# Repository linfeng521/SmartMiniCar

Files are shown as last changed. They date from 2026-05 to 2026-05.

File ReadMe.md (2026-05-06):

# 练习项目三、1.3智能小车
## 一、项目思路
智能小车项目的整体思路是：以主控芯片为核心，结合电机驱动模块控制小车运动，通过传感器采集小车运行状态，再利用 PID 控制算法对小车的速度、方向或循迹过程进行实时调节，使小车能够更加稳定、准确地完成前进、转弯、避障或循迹等任务。
其中，PID 的作用是根据目标值和实际值之间的误差进行动态调整，从而提高小车运行的平稳性和控制精度。
## 二、项目功能
1. 小车运动控制功能
能够实现前进、后退、左转、右转和停止等基本动作。

2. PID 速度调节功能
通过 PID 算法对电机转速进行闭环控制，使小车保持稳定速度运行。
3. PID 方向修正功能
在循迹或直线行驶过程中，通过 PID 对偏差进行修正，提高行驶稳定性。
4. 循迹功能
通过红外传感器检测地面轨迹，小车能够沿指定路线自动行驶。
5. 避障功能
通过超声波等传感器检测前方障碍物，在接近障碍物时自动减速、停止或绕行。
6. 状态显示功能
可通过 OLED 或其他显示模块显示当前速度、运行模式、传感器状态等信息。
## 三、硬件组成
1. 主控模块
作为整个小车系统的核心，用于采集传感器信息、执行 PID 算法并输出控制信号。
> stm32f103c8t6
2. 电机驱动模块
用于驱动左右电机运转，实现小车前进、后退和转向。
TB6612FNG电机驱动模块(替代旧款L298N)
> 双路 H 桥电机驱动芯片,可以驱动两路直流电机
3. 直流减速电机
作为小车的动力来源，带动车轮运动。
2个轮趣MG370直流减速电机P34_12V 霍尔编码器
> 电机资料：https://pan.baidu.com/s/1y1XS6GmnZMquCIRk9muSQg 【WHEELTEC】
> 减速比：1:34
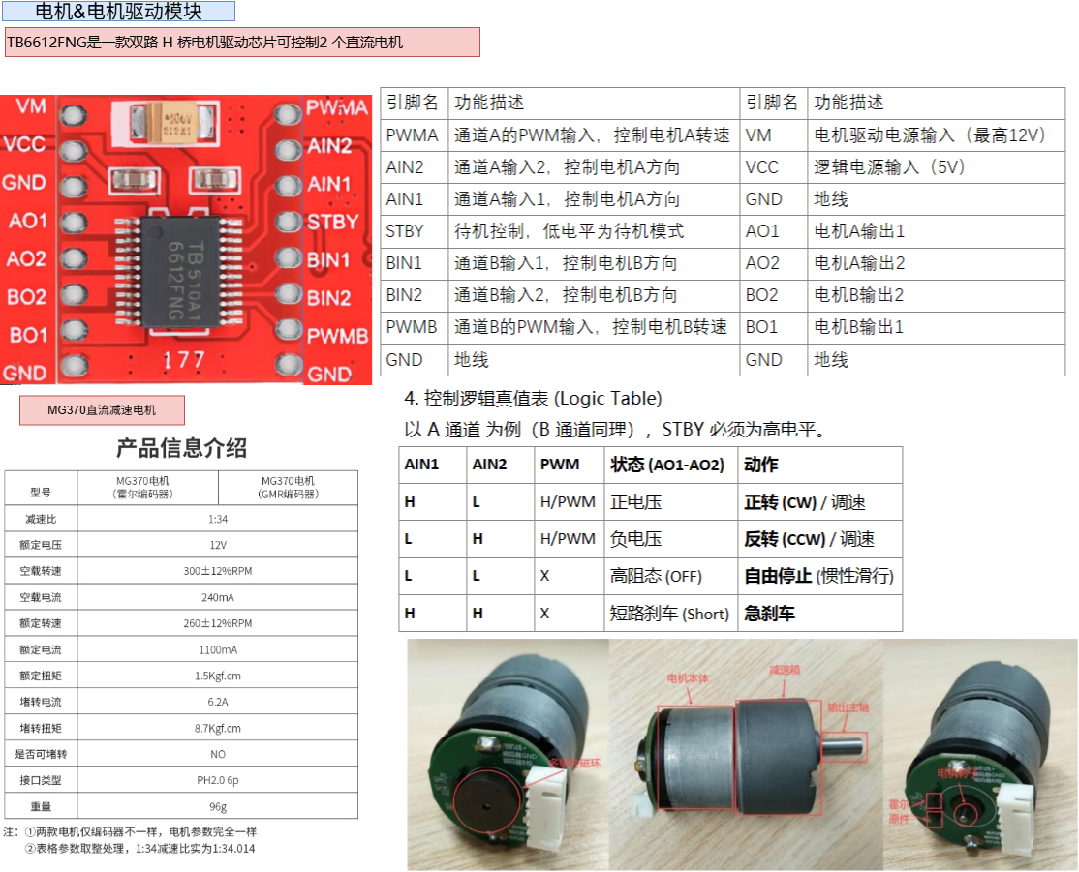
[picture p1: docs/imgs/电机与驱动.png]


4. 编码器模块
用于检测电机转速或车轮转动情况，为 PID 闭环控制提供反馈数据。
> 电机尾部霍尔编码器AB相
> 电机的编码器精度为 13
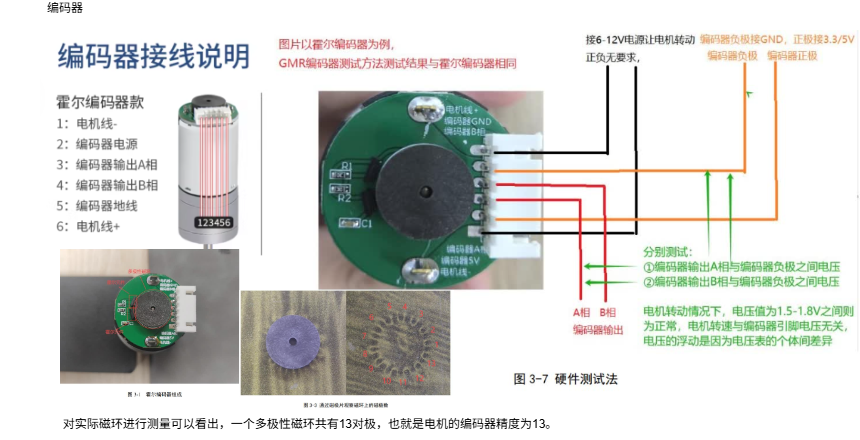
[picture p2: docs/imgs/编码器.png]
编码器

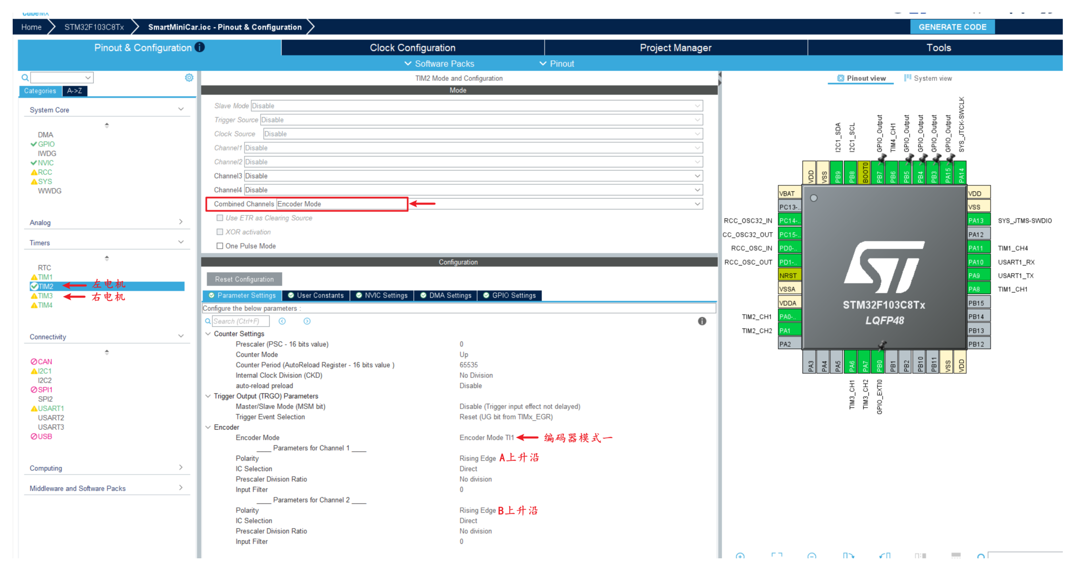
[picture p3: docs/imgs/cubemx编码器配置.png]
cubemx编码器配置


5. 霍尔转速模块
用于辅助检测电机转速，一圈一个脉冲

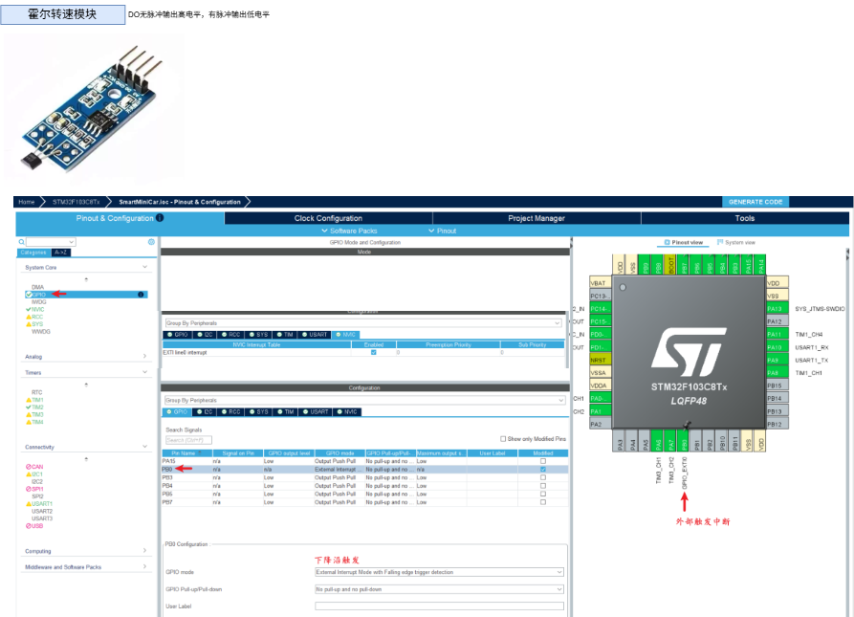
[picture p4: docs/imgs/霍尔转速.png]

~~ 5. 红外循迹传感器 ~~
用于检测地面黑线或路径，实现小车自动循迹。
6. 超声波模块
用于检测前方障碍物距离，实现避障功能。

> 超声波模块：HC-SR04超声波传感器

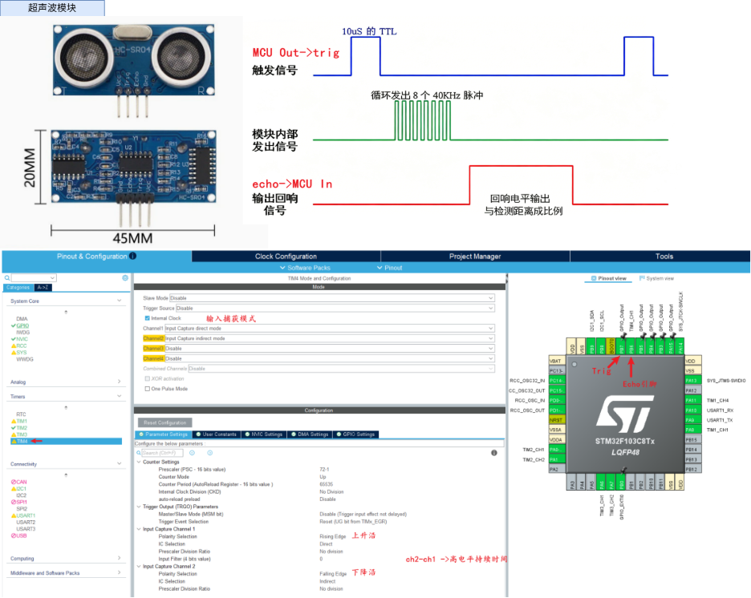
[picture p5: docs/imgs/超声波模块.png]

7. OLED 显示屏
用于显示速度、模式、传感器数据和运行状态。
> 屏幕：OLED 128*64 屏幕
8. 电源模块
为主控、电机驱动、传感器和显示模块提供稳定电源。
> 电源：德力普12V 1800mAh【3节一字型】
> 升降压模块：TPS63020 DCDC直流锂电池开关电源 2035升降压 5V输出输入3-20V

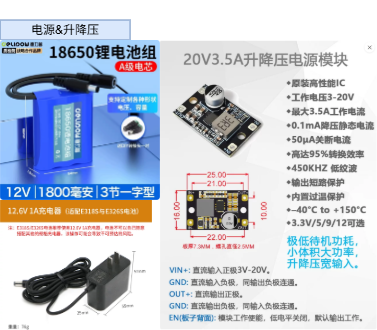
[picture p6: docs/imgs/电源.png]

9. 车体结构
包括底盘、车轮、电机固定架和各模块安装支架。
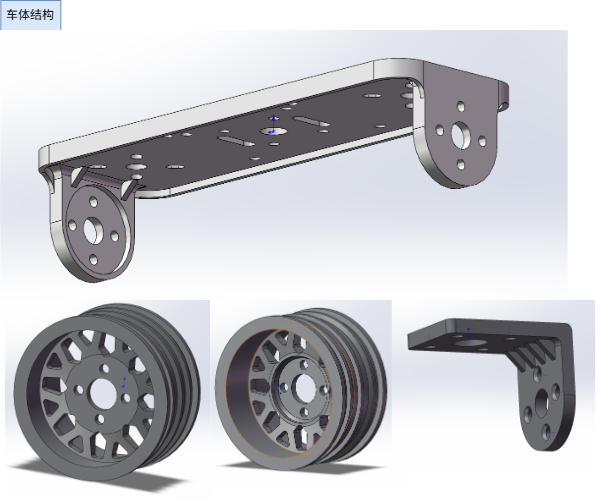
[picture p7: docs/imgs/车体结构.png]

## 四、软件组成

### 4.1 根据项目功能，引脚分配如下：
#### TB6612 电机驱动引脚

| 功能 | 引脚 | 说明 |
|---|---|---|
| PWMA | PA8 (TIM1_CH1) | 左电机 PWM，高级定时器支持 |
| PWMB | PA11 (TIM1_CH4) | 右电机 PWM |
| AIN1 | PB5 | 左电机方向控制1 |
| AIN2 | PB4 | 左电机方向控制2 |
| BIN1 | PB3 | 右电机方向控制1 |
| BIN2 | PA15 | 右电机方向控制2 |
| STBY | PA12 | 驱动使能，高电平有效(待定 现在直接使用接了3.3V) |

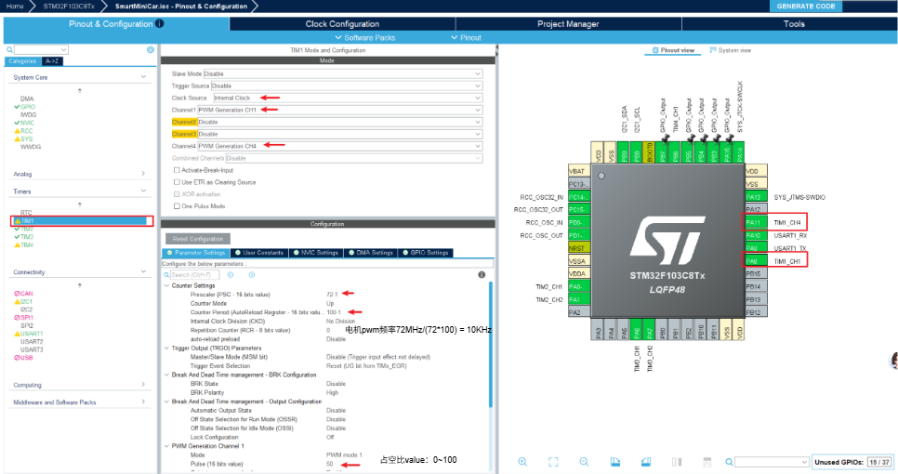
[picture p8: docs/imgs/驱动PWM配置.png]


#### 编码器引脚（霍尔编码器）

| 功能 | 引脚 | 说明 |
|---|---|---|
| 左编码器 A 相 | PA0 (TIM2_CH1) | TIM2 编码器模式 |
| 左编码器 B 相 | PA1 (TIM2_CH2) | TIM2 编码器模式 |
| 右编码器 A 相 | PA6 (TIM3_CH1) | TIM3 编码器模式 |
| 右编码器 B 相 | PA7 (TIM3_CH2) | TIM3 编码器模式 |

详见驱动模块：[编码器驱动](BSP/Encoder/encoder.c)
```c
// 启动定时器编码器模式
HAL_TIM_Encoder_Start(&htim2, TIM_CHANNEL_ALL);
HAL_TIM_Encoder_Start(&htim3, TIM_CHANNEL_ALL);

// 重置计数
__HAL_TIM_SET_COUNTER(&htim2, 0);
__HAL_TIM_SET_COUNTER(&htim3, 0);

//获取计数
__HAL_TIM_GET_COUNTER(&htim2);
__HAL_TIM_GET_COUNTER(&htim3)
```
#### 霍尔测速模块
无触发时为高电平，有触发时为低电平
| 功能 | 引脚 | 说明 |
|---|---|---|
| 电机霍尔测速器 | PB0 | GPIO EXTI0 外部中断输入，霍尔测速信号 |

[霍尔测速驱动](BSP/Hall/hall.c)

#### 超声波模块引脚

| 功能 | 引脚 | 说明 |
|---|---|---|
| Trig | PB7 | GPIO 输出，触发信号 |
| Echo | PB6 | GPIO 输入，回波信号(可接 TIM4 输入捕获) |

[超声波模块驱动](BSP/HCSR04/hcsr04.c)

#### OLED 显示屏引脚 && MPU6050 (I2C)

| 功能 | 引脚 | 说明 |
|---|---|---|
| SCL | PB8 (I2C1_SCL) | I2C1 时钟线 |
| SDA | PB9 (I2C1_SDA) | I2C1 数据线 |

#### 串口调试引脚

| 功能 | 引脚 | 说明 |
|---|---|---|
| uart_tx | PA9  | TX 数据线 |
| uart_rx | PA10 | RX 数据线 |

### 4.2 定时器配置

#### TIM1 — 电机 PWM

- Clock Source: Internal Clock
- Channel1 (PWMA): PWM Generation CH1
- Channel4 (PWMB): PWM Generation CH4
- Prescaler (PSC): 71 → 计数频率 = 72MHz / 72 = 1 MHz
- Counter Period (ARR): 99 → PWM 频率 = 1MHz / 100 = 10 kHz
- Pulse (CCR): 0~999 → 占空比 0~100%

> PWM 频率选择: TB6612 支持 0~100kHz，10kHz 是常用值，电机声音较小

#### TIM2 — 左编码器

- Combined Channel: Encoder Mode TI1
- Prescaler (PSC): 0
- Counter Period (ARR): 65535 (16位满量程)
- Encoder Polarity: Rising / Rising
- 计数模式: Up

#### TIM3 — 右编码器

- 同 TIM2 配置

#### TIM4 — 超声波输入捕获

- TIM4_CH1：Input Capture Direct Mode（直接模式）
  极性：Rising Edge 上升沿
- TIM4_CH2：Input Capture Indirect Mode（间接模式）
  极性：Falling Edge 下降沿
- Prescaler: 71 → 计数频率 = 1 MHz，1计数 = 1μs
- 用于测量 Echo 高电平持续时间

## 五、分模块测试
1、电机测试（PWM）

2、编码器测试

3、超声波测距测试

4、OLED 显示测试

5、霍尔转速测试

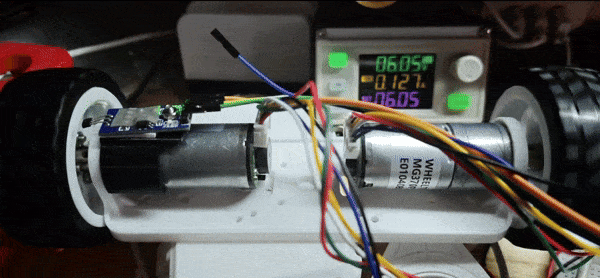
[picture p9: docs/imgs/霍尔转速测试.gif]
霍尔转速


6、总体功能测试
```c
while (1)
  {
    uint32_t now = HAL_GetTick();

    /*串口命令*/
    if (uart_cmd_ready != 0U)
    {
      char command[UART_COMMAND_MAX_LEN];

      __disable_irq();
      strncpy(command, uart_cmd_line, sizeof(command));
      uart_cmd_ready = 0U;
      __enable_irq();

      printf("recv:%s\r\n", command);

      Motor_ParseCommand(command);
    }

    /*编码器*/
    if ((now - encoder_tick) >= 100)
    {
      encoder_tick = now;

      left_rps = Encoder_GetRPS(ENCODER_LEFT);
      right_rps = Encoder_GetRPS(ENCODER_RIGHT);

      printf("encoder:left_rps=%f,right_rps=%f\r\n", left_rps, right_rps);
    }

    /*霍尔*/
    if ((now - hall_tick) >= 100)
    {
      hall_tick = now;

      printf("hall:PulseCnt=%d,left_rpm=%d,freq=%f\r\n", Hall_GetPulse(), Hall_GetRPM(), Hall_GetRPS());
    }

    /*超声波*/
    if ((now - ultrasonic_tick) >= 50)
    {
      ultrasonic_tick = now;

      HCSR04_Trigger();
      distance_cm = HCSR04_GetDistanceCm();

      printf("dist=%.1fcm\r\n", distance_cm);
    }

    /*OLED显示*/
    if ((now - oled_tick) >= 200)
    {
      oled_tick = now;
      // 左电机编码器(tim2 encoder)
      sprintf(oled_buf, "ML:%5.2f rps", left_rps);
      OLED_ShowString(0, 0, oled_buf, 16, 0);
      // 右电机编码器(tim3 encoder)
      sprintf(oled_buf, "MR:%5.2f rps", right_rps);
      OLED_ShowString(0, 2, oled_buf, 16, 0);
      // 左电机霍尔转速（exti0)
      sprintf(oled_buf, "LH:%5.2f rps", Hall_GetRPS());
      OLED_ShowString(0, 4, oled_buf, 16, 0);
      // 超声波测距(tim3 ic)
      sprintf(oled_buf, "D:%5.1fCM", distance_cm);
      OLED_ShowString(0, 6, oled_buf, 16, 0);
    }
```
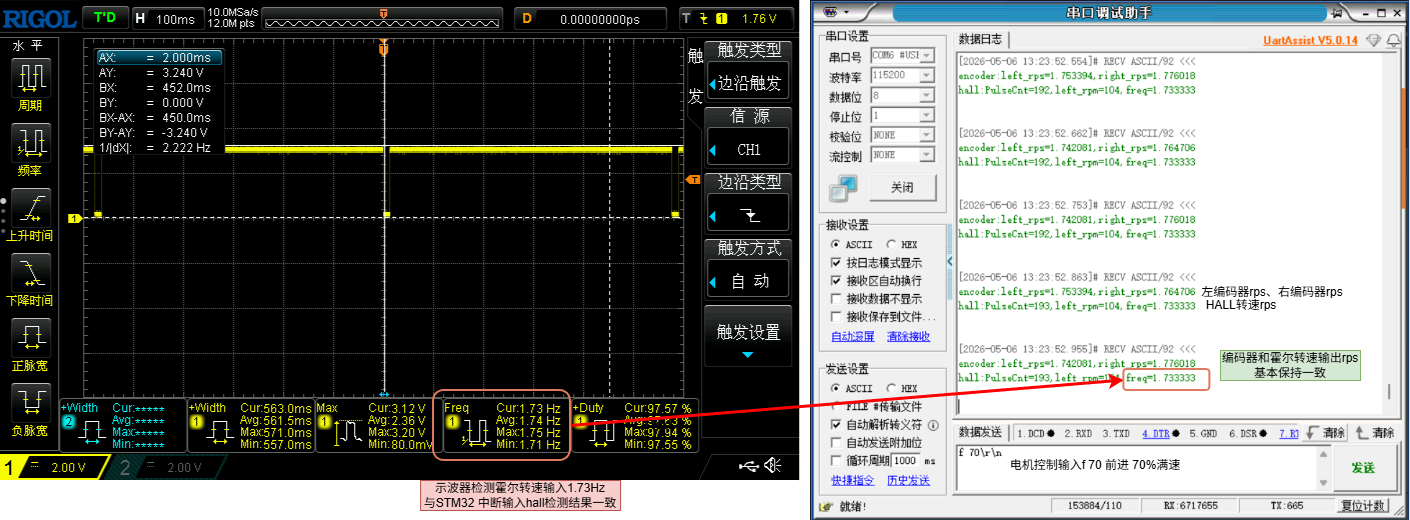
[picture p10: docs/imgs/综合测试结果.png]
测试结果


拍照

[阶段1视频](https://github.com/linfeng521/SmartMiniCar/blob/main/docs/imgs/阶段1.mp4)

[在线drawio文档笔记](https://app.diagrams.net/#Hlinfeng521/SmartMiniCar/main/docs/智能小车.drawio)

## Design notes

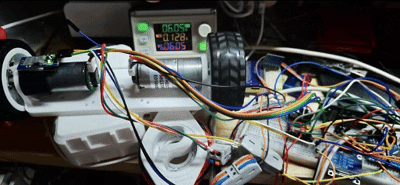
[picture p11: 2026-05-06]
docs/imgs/948157eb1a8de07d441068f1ed50d3bd.gif

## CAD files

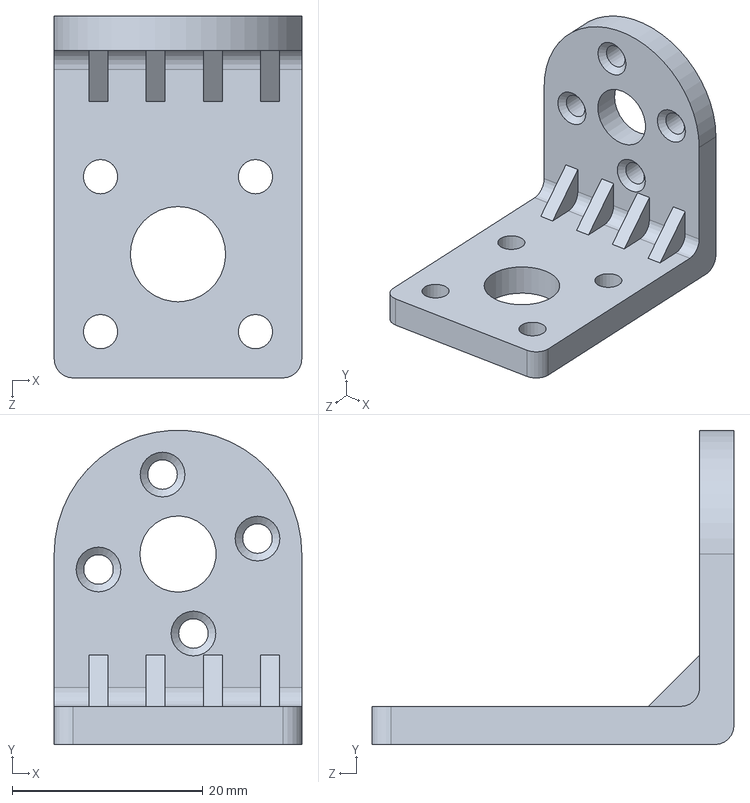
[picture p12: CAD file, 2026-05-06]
docs/MG370直流减速电机支架加厚加肋板.SLDPRT
26.0 x 33.0 x 38.0 mm

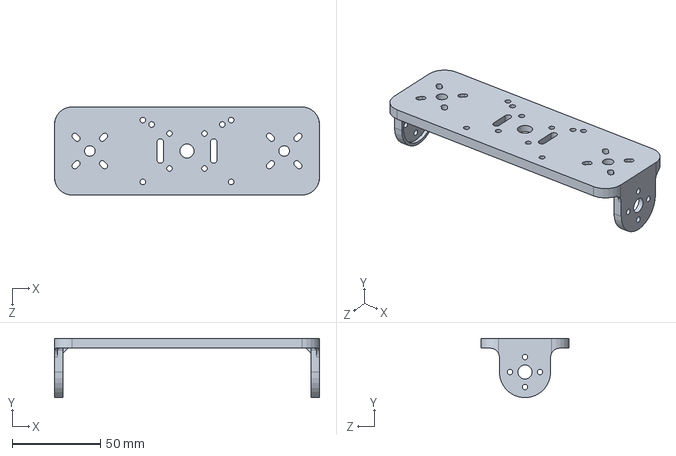
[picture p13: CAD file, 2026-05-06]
docs/平衡车底板一体.SLDPRT
150.0 x 33.6 x 50.0 mm

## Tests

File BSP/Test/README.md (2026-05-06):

# 模块化测试系统使用指南

## 📁 文件结构

```
BSP/
├── Test/
│   ├── test.h              # 测试接口头文件
│   ├── test.c              # 测试实现文件
│   ├── test_example.c      # 使用示例
│   └── README.md           # 本文档
├── Motor/
│   ├── motor.h
│   ├── motor.c
│   └── motor_test.md       # 电机测试指南
├── Encoder/
│   ├── encoder.h
│   └── encoder.c
└── HCSR04/
    ├── hcsr04.h
    └── hcsr04.c
```

## 🚀 快速开始

### 1. 添加文件到工程

在 Keil MDK 或 STM32CubeIDE 中：
1. 将 `test.c` 添加到工程
2. 将 `BSP/Test` 路径添加到 Include Paths

### 2. 在 main.c 中添加代码

```c
#include "test.h"

int main(void)
{
    // ... HAL 初始化 ...
    
    Motor_Init();
    Encoder_Init();
    HCSR04_Init();
    
    Test_Init();        // 初始化测试系统
    Test_PrintMenu();   // 显示测试菜单
    
    while (1)
    {
        // 方法1: 直接调用
        Test_Motor_Left();
        HAL_Delay(3000);
        
        // 方法2: 通过枚举
        Test_RunModule(TEST_MOTOR_RIGHT);
        HAL_Delay(3000);
    }
}
```

### 3. 通过串口控制（推荐）

发送单个字符命令：
- `0` - 测试左电机
- `1` - 测试右电机
- `2` - 测试前进
- `3` - 测试后退
- `4` - 测试左转
- `5` - 测试右转
- `6` - 测试原地左旋
- `7` - 测试原地右旋
- `8` - 测试左编码器
- `9` - 测试右编码器
- `a` - 测试双编码器
- `b` - 测试超声波
- `c` - 电机编码器同步测试
- `d` - 运行所有测试
- `m` - 显示菜单

## 📋 测试模块说明

### 电机测试

#### 1. 单电机测试 (`Test_Motor_Left` / `Test_Motor_Right`)
**目的**: 判断左右电机定义是否正确

**步骤**:
1. 调用 `Test_Motor_Left()`
2. 观察：应该是**左侧**电机转动
3. 如果是右侧转动，说明定义颠倒了

**预期输出**:
```
[测试] 左电机测试
左电机将以 50% 速度运行 2000 ms
请观察：应该是【左侧】电机转动
左电机测试完成
```

#### 2. 前进/后退测试 (`Test_Motor_Forward` / `Test_Motor_Backward`)
**目的**: 验证电机方向是否正确

**判断标准**:
- ✅ 前进：小车向前移动
- ✅ 后退：小车向后移动
- ❌ 如果相反，需要调整电机方向引脚

#### 3. 转向测试 (`Test_Motor_TurnLeft` / `Test_Motor_TurnRight`)
**目的**: 验证转向逻辑

**判断标准**:
- ✅ 左转：小车向左转弯（左轮慢，右轮快）
- ✅ 右转：小车向右转弯（右轮慢，左轮快）
- ❌ 如果相反，说明左右电机定义颠倒

#### 4. 原地旋转测试 (`Test_Motor_RotateLeft` / `Test_Motor_RotateRight`)
**目的**: 验证原地旋转功能

**判断标准**:
- ✅ 左旋：逆时针旋转（左轮后退，右轮前进）
- ✅ 右旋：顺时针旋转（左轮前进，右轮后退）

### 编码器测试

#### 1. 单编码器测试 (`Test_Encoder_Left` / `Test_Encoder_Right`)
**目的**: 验证编码器方向

**预期输出**:
```
[测试] 左编码器测试
左电机将前进 2000 ms，测量编码器计数
左编码器计数: 1234
方向: 前进
✓ 编码器方向正确（前进为正）
```

**判断标准**:
- ✅ 前进时计数为**正数**
- ❌ 前进时计数为**负数** → 编码器接线反了
- ❌ 计数为 0 → 检查编码器接线或 CubeMX 配置

#### 2. 双编码器同步测试 (`Test_Encoder_Both`)
**目的**: 检查两轮速度是否一致

**预期输出**:
```
[测试] 双编码器同步测试
小车将前进 2000 ms，测量两个编码器
左编码器: 1234
右编码器: 1256
差异: -22 (-1.8%)
✓ 两个编码器方向都正确
✓ 两轮速度基本一致
```

**判断标准**:
- ✅ 差异 < 10% → 速度基本一致
- ⚠️ 差异 > 10% → 可能需要 PID 校准

#### 3. 电机编码器同步测试 (`Test_Motor_Encoder_Sync`)
**目的**: 全面验证电机和编码器匹配

**测试流程**:
1. 前进 1 秒，记录编码器值
2. 后退 1 秒，记录编码器值
3. 分析结果

**预期输出**:
```
[测试] 电机编码器同步测试
1. 测试前进...
   左: 1234, 右: 1256
2. 测试后退...
   左: -1230, 右: -1250

结果分析:
✓ 电机和编码器方向完全匹配
```

### 传感器测试

#### HC-SR04 超声波测试 (`Test_HCSR04`)
**目的**: 验证超声波测距功能

**预期输出**:
```
[测试] HC-SR04 超声波测试
将连续测量 10 次距离
[1] 距离: 25.3 cm
[2] 距离: 25.5 cm
[3] 距离: 25.2 cm
...
```

**判断标准**:
- ✅ 能测量到距离（2-400cm）
- ✅ 数值稳定，波动小
- ❌ 显示 -1.0 → 超出测量范围
- ❌ 超时 → 检查接线或 CubeMX 配置

## 🔧 常见问题排查

### 问题1: 左右电机颠倒

**现象**: 调用 `Test_Motor_Left()` 时右侧电机转动

**解决方法**: 在 `motor.h` 中交换 A 和 B 的引脚定义
```c
// 交换前
#define MOTOR_AIN1_PIN GPIO_PIN_5
#define MOTOR_BIN1_PIN GPIO_PIN_3

// 交换后
#define MOTOR_AIN1_PIN GPIO_PIN_3
#define MOTOR_BIN1_PIN GPIO_PIN_5
```

### 问题2: 前进变后退

**现象**: 调用 `Test_Motor_Forward()` 时小车后退

**解决方法**: 在 `motor.c` 的 `Motor_SetDirection()` 中交换 SET 和 RESET

### 问题3: 编码器计数为负

**现象**: 前进时编码器显示负数

**解决方法**: 
1. 交换编码器 A/B 相接线
2. 或在 CubeMX 中修改编码器模式（TI1/TI2 互换）

### 问题4: 编码器无计数

**现象**: 电机转动但编码器计数为 0

**排查步骤**:
1. 检查编码器供电（通常 3.3V 或 5V）
2. 检查 A/B 相接线是否正确
3. 检查 CubeMX 中定时器配置（Encoder Mode）
4. 用示波器测量编码器输出波形

### 问题5: 超声波无数据

**现象**: 超声波测试一直超时

**排查步骤**:
1. 检查 TRIG 和 ECHO 接线
2. 检查 CubeMX 中 TIM4 配置（Input Capture）
3. 确认前方有障碍物（2-400cm 范围内）
4. 检查中断是否使能

## 💡 使用技巧

### 1. 快速诊断流程

```c
// 在 main 函数中添加
Test_Init();

// 步骤1: 测试左右电机
Test_Motor_Left();
HAL_Delay(3000);
Test_Motor_Right();
HAL_Delay(3000);

// 步骤2: 测试前进
Test_Motor_Forward();
HAL_Delay(3000);

// 步骤3: 测试编码器同步
Test_Motor_Encoder_Sync();

// 根据输出结果判断问题
```

### 2. 串口交互式测试（推荐）

```c
// 在串口接收回调中
void HAL_UART_RxCpltCallback(UART_HandleTypeDef *huart)
{
    if (huart->Instance == USART1) {
        char cmd = rx_buffer[0];
        
        if (cmd >= '0' && cmd <= '9') {
            Test_RunModule((Test_Module_TypeDef)(cmd - '0'));
        } else if (cmd == 'a' || cmd == 'A') {
            Test_RunModule(TEST_ENCODER_BOTH);
        }
        // ... 其他命令
        
        HAL_UART_Receive_IT(&huart1, rx_buffer, 1);
    }
}
```

### 3. 自动化测试

```c
// 开机自动运行所有测试
Test_Init();
Test_RunModule(TEST_ALL);
```

## 📊 测试报告示例

```
========================================
  SmartMiniCar 模块测试系统
========================================

[测试] 左电机测试
✓ 左侧电机正常转动

[测试] 右电机测试
✓ 右侧电机正常转动

[测试] 前进测试
✓ 小车正常前进

[测试] 双编码器同步测试
左编码器: 1234
右编码器: 1256
差异: -22 (-1.8%)
✓ 两个编码器方向都正确
✓ 两轮速度基本一致

[测试] HC-SR04 超声波测试
[1] 距离: 25.3 cm
[2] 距离: 25.5 cm
✓ 超声波工作正常

========================================
测试结论: 所有模块工作正常
========================================
```

## 🎯 下一步

测试通过后，可以开始：
1. 实现 PID 速度控制
2. 实现避障功能
3. 实现循迹功能
4. 实现蓝牙/WiFi 控制

参考 `motor_test.md` 获取更多电机调试信息。

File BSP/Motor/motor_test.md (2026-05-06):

# 电机测试指南

## 如何判断左右电机是否颠倒

### 测试步骤：

1. **单独测试左电机**
   ```c
   Motor_TestLeftMotor(50, 2000);  // 左电机以50%速度运行2秒
   ```
   - 观察：应该是**左侧**电机转动
   - 如果是右侧电机转动，说明定义颠倒了

2. **单独测试右电机**
   ```c
   Motor_TestRightMotor(50, 2000);  // 右电机以50%速度运行2秒
   ```
   - 观察：应该是**右侧**电机转动
   - 如果是左侧电机转动，说明定义颠倒了

3. **测试前进**
   ```c
   Motor_Forward(50);  // 前进
   HAL_Delay(2000);
   Motor_StopAll();
   ```
   - 观察：两个电机应该**同向转动**，小车**前进**
   - 如果小车后退，说明两个电机方向都反了
   - 如果小车原地转，说明一个电机方向反了

4. **测试转向**
   ```c
   Motor_TurnLeft(50);   // 左转
   HAL_Delay(2000);
   Motor_StopAll();
   ```
   - 观察：小车应该**向左转**
   - 如果向右转，说明左右电机定义颠倒了

## 如果发现问题，修复方法：

### 方法1：交换硬件定义（推荐）

在 `motor.h` 中交换 A 和 B 的引脚定义：

```c
// 原来的定义
#define MOTOR_AIN1_PIN GPIO_PIN_5    // 左电机
#define MOTOR_AIN1_PORT GPIOB
#define MOTOR_AIN2_PIN GPIO_PIN_4
#define MOTOR_AIN2_PORT GPIOB

#define MOTOR_BIN1_PIN GPIO_PIN_3    // 右电机
#define MOTOR_BIN1_PORT GPIOB
#define MOTOR_BIN2_PIN GPIO_PIN_15
#define MOTOR_BIN2_PORT GPIOA

// 如果颠倒了，改成：
#define MOTOR_AIN1_PIN GPIO_PIN_3    // 交换
#define MOTOR_AIN1_PORT GPIOB
#define MOTOR_AIN2_PIN GPIO_PIN_15
#define MOTOR_AIN2_PORT GPIOA

#define MOTOR_BIN1_PIN GPIO_PIN_5    // 交换
#define MOTOR_BIN1_PORT GPIOB
#define MOTOR_BIN2_PIN GPIO_PIN_4
#define MOTOR_BIN2_PORT GPIOB
```

### 方法2：交换 PWM 通道

在 `motor.c` 的 `Motor_SetPWM()` 函数中交换通道：

```c
switch (motor) {
case MOTOR_LEFT:
    __HAL_TIM_SET_COMPARE(&htim1, TIM_CHANNEL_4, pwm);  // 改成 CHANNEL_4
    break;

case MOTOR_RIGHT:
    __HAL_TIM_SET_COMPARE(&htim1, TIM_CHANNEL_1, pwm);  // 改成 CHANNEL_1
    break;
}
```

### 方法3：如果只是方向反了

如果左右没颠倒，但前进变后退，在 `Motor_SetDirection()` 中交换 SET 和 RESET：

```c
case MOTOR_DIR_FORWARD:
    // 把 GPIO_PIN_SET 和 GPIO_PIN_RESET 互换
    HAL_GPIO_WritePin(MOTOR_AIN1_PORT, MOTOR_AIN1_PIN, GPIO_PIN_RESET);
    HAL_GPIO_WritePin(MOTOR_AIN2_PORT, MOTOR_AIN2_PIN, GPIO_PIN_SET);
    break;
```

## 编码器方向测试

测试编码器是否与电机方向匹配：

```c
Encoder_ResetAll();
Motor_Forward(50);
HAL_Delay(1000);
Motor_StopAll();

int16_t left_count = Encoder_GetDeltaCount(ENCODER_LEFT);
int16_t right_count = Encoder_GetDeltaCount(ENCODER_RIGHT);

printf("Left: %d, Right: %d\n", left_count, right_count);
```

- 前进时，两个编码器计数应该都是**正数**
- 如果某个是负数，说明该编码器接线反了，或者在 CubeMX 中配置反了

## 串口命令测试

通过串口发送以下命令测试：

- `F 50` - 前进，速度50%
- `B 50` - 后退，速度50%
- `L 50` - 左转
- `R 50` - 右转
- `RL 50` - 原地左旋
- `RR 50` - 原地右旋
- `M 30 50` - 左轮30%，右轮50%
- `STOP` - 停止

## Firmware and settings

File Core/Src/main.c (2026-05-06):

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
/* Includes ------------------------------------------------------------------*/
#include "main.h"
#include "i2c.h"
#include "tim.h"
#include "usart.h"
#include "gpio.h"

/* USER CODE BEGIN Includes */
#include <stdio.h>
#include <string.h>
#include "encoder.h"
#include "hall.h"
#include "motor.h"
#include "hcsr04.h"
#include "ssd1306.h"
/* USER CODE END Includes */

/* USER CODE BEGIN PD */
#define UART_COMMAND_MAX_LEN 64

/* USER CODE END PD */


/* USER CODE BEGIN PV */
static uint8_t uart_rx_byte;
static char uart_rx_line[UART_COMMAND_MAX_LEN];
static char uart_cmd_line[UART_COMMAND_MAX_LEN];
static volatile uint8_t uart_rx_index = 0;
static volatile uint8_t uart_cmd_ready = 0;

uint32_t hall_tick = 0;
uint32_t encoder_tick = 0;
uint32_t oled_tick = 0;
uint32_t ultrasonic_tick = 0;
char oled_buf[36] = ""; // oled显示

float left_rps = 0.0f;
float right_rps = 0.0f;
float distance_cm = 0.0f;

/* USER CODE END PV */

void SystemClock_Config(void);
/* USER CODE BEGIN PFP */
static void UART_StartReceiveIT(void);

/* USER CODE END PFP */

/* USER CODE BEGIN 0 */
// 串口重定向
int fputc(int ch, FILE *f)
{
  HAL_UART_Transmit(&huart1, (uint8_t *)&ch, 1, HAL_MAX_DELAY);
  return ch;
}

// 启动串口1的中断接收
static void UART_StartReceiveIT(void)
{
  if (HAL_UART_Receive_IT(&huart1, &uart_rx_byte, 1) != HAL_OK)
  {
    Error_Handler();
  }
}

// exti0 中断回调
void HAL_GPIO_EXTI_Callback(uint16_t GPIO_Pin)
{
  Hall_EXTI_Callback(GPIO_Pin);
}

/* USER CODE END 0 */

/**
 * @brief  The application entry point.
 * @retval int
 */
int main(void)
{

  /* MCU Configuration--------------------------------------------------------*/

  /* Reset of all peripherals, Initializes the Flash interface and the Systick. */
  HAL_Init();

  /* Configure the system clock */
  SystemClock_Config();

  /* Initialize all configured peripherals */
  MX_GPIO_Init();
  MX_I2C1_Init();
  MX_TIM1_Init();
  MX_TIM2_Init();
  MX_TIM3_Init();
  MX_TIM4_Init();
  MX_USART1_UART_Init();
  /* USER CODE BEGIN 2 */
  // 编码器初始化
  Encoder_Init();
  // 超声波测距初始化
  HCSR04_Init();
  // 左右减速电机&驱动模块初始化
  Motor_Init();
  // 配置 USART2 接收中断
  UART_StartReceiveIT();
  printf("UART motor control ready\r\n");
  printf("Commands: STOP | BRAKE | F 60 | B 60 | L 60 | R 60 | RL 60 | RR 60 | M -30 50\r\n");

  if (OLED_Init(&hi2c1) != HAL_OK)
  {
    Error_Handler();
  }
  OLED_Clear();
  /* USER CODE END 2 */

  /* Infinite loop */
  /* USER CODE BEGIN WHILE */
  while (1)
  {
    uint32_t now = HAL_GetTick();

    /*串口命令*/
    if (uart_cmd_ready != 0U)
    {
      char command[UART_COMMAND_MAX_LEN];

      __disable_irq();
      strncpy(command, uart_cmd_line, sizeof(command));
      uart_cmd_ready = 0U;
      __enable_irq();

      printf("recv:%s\r\n", command);

      Motor_ParseCommand(command);
    }

    /*编码器*/
    if ((now - encoder_tick) >= 100)
    {
      encoder_tick = now;

      left_rps = Encoder_GetRPS(ENCODER_LEFT);
      right_rps = Encoder_GetRPS(ENCODER_RIGHT);

      printf("encoder:left_rps=%f,right_rps=%f\r\n", left_rps, right_rps);
    }

    /*霍尔*/
    if ((now - hall_tick) >= 100)
    {
      hall_tick = now;

      printf("hall:PulseCnt=%d,left_rpm=%d,freq=%f\r\n", Hall_GetPulse(), Hall_GetRPM(), Hall_GetRPS());
    }

    /*超声波*/
    if ((now - ultrasonic_tick) >= 50)
    {
      ultrasonic_tick = now;

      HCSR04_Trigger();
      distance_cm = HCSR04_GetDistanceCm();

      printf("dist=%.1fcm\r\n", distance_cm);
    }

    /*OLED显示*/
    if ((now - oled_tick) >= 200)
    {
      oled_tick = now;
      // 左电机编码器(tim2 encoder)
      sprintf(oled_buf, "ML:%5.2f rps", left_rps);
      OLED_ShowString(0, 0, oled_buf, 16, 0);
      // 右电机编码器(tim3 encoder)
      sprintf(oled_buf, "MR:%5.2f rps", right_rps);
      OLED_ShowString(0, 2, oled_buf, 16, 0);
      // 左电机霍尔转速（exti0)
      sprintf(oled_buf, "LH:%5.2f rps", Hall_GetRPS());
      OLED_ShowString(0, 4, oled_buf, 16, 0);
      // 超声波测距(tim3 ic)
      sprintf(oled_buf, "D:%5.1fCM", distance_cm);
      OLED_ShowString(0, 6, oled_buf, 16, 0);
    }

    /* USER CODE END WHILE */

    /* USER CODE BEGIN 3 */
  }
  /* USER CODE END 3 */
}

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
/* USER CODE BEGIN 4 */
void HAL_UART_RxCpltCallback(UART_HandleTypeDef *huart)
{
  if (huart->Instance == USART1)
  {
    if ((uart_rx_byte == '\r') || (uart_rx_byte == '\n'))
    {
      if (uart_rx_index > 0U)
      {
        uart_rx_line[uart_rx_index] = '\0';
        if (uart_cmd_ready == 0U)
        {
          strncpy(uart_cmd_line, uart_rx_line, UART_COMMAND_MAX_LEN);
          uart_cmd_ready = 1U;
        }
        uart_rx_index = 0U;
      }
    }
    else if (uart_rx_index < (UART_COMMAND_MAX_LEN - 1U))
    {
      uart_rx_line[uart_rx_index++] = (char)uart_rx_byte;
    }
    else
    {
      uart_rx_index = 0U;
    }

    // 继续接收
    HAL_UART_Receive_IT(&huart1, &uart_rx_byte, 1);
  }
}

void HAL_UART_ErrorCallback(UART_HandleTypeDef *huart)
{
  if (huart->Instance == USART1)
  {
    uart_rx_index = 0U;
    UART_StartReceiveIT();
  }
}

/* USER CODE END 4 */
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


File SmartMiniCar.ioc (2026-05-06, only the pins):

Mcu.UserName=STM32F103C8Tx
PA0-WKUP.Signal=S_TIM2_CH1_ETR
PA1.Signal=S_TIM2_CH2
PA10.Signal=USART1_RX
PA11.Signal=S_TIM1_CH4
PA13.Signal=SYS_JTMS-SWDIO
PA14.Signal=SYS_JTCK-SWCLK
PA15.Signal=GPIO_Output
PA6.Signal=S_TIM3_CH1
PA7.Signal=S_TIM3_CH2
PA8.Signal=S_TIM1_CH1
PA9.Signal=USART1_TX
PB0.Signal=GPXTI0
PB3.Signal=GPIO_Output
PB4.Signal=GPIO_Output
PB5.Signal=GPIO_Output
PB6.Signal=S_TIM4_CH1
PB7.Signal=GPIO_Output
PB8.Signal=I2C1_SCL
PB9.Signal=I2C1_SDA
PC14-OSC32_IN.Signal=RCC_OSC32_IN
PC15-OSC32_OUT.Signal=RCC_OSC32_OUT
PD0-OSC_IN.Signal=RCC_OSC_IN
PD1-OSC_OUT.Signal=RCC_OSC_OUT

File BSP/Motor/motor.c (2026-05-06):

/**
  ******************************************************************************
  * @file    motor.c
  * @brief   TB6612 电机驱动实现
  * @note    PWM 频率: 72MHz / 72 / 100 = 10kHz
  ******************************************************************************
  */

#include "motor.h"

#include <ctype.h>
#include <stdio.h>
#include <stdlib.h>
#include <string.h>

// 限制速度在有效 PWM 范围内。
static int Motor_ClampPercent(int value)
{
    
    if (value > MOTOR_PWM_MAX) {
        return MOTOR_PWM_MAX;
    }

    if (value < -MOTOR_PWM_MAX) {
        return -MOTOR_PWM_MAX;
    }

    return value;
}

static void Motor_ToUpperToken(char *token)
{
    // 统一转成大写，方便命令匹配。
    while (*token != '\0') {
        *token = (char)toupper((unsigned char)*token);
        token++;
    }
}

// 初始化电机：先启动 PWM，再让电机停住。
void Motor_Init(void)
{
    HAL_TIM_PWM_Start(&htim1, TIM_CHANNEL_1);
    HAL_TIM_PWM_Start(&htim1, TIM_CHANNEL_4);
    Motor_StopAll();
}

// 设置某个电机的方向。
static void Motor_SetDirection(Motor_TypeDef motor, Motor_Direction_TypeDef dir)
{
    // 通过 TB6612 的方向引脚控制前进、后退和停止。
    switch (motor) {
    case MOTOR_LEFT:
        switch (dir) {
        case MOTOR_DIR_FORWARD:
					// 1 0正转
            HAL_GPIO_WritePin(MOTOR_AIN1_PORT, MOTOR_AIN1_PIN, GPIO_PIN_SET);
            HAL_GPIO_WritePin(MOTOR_AIN2_PORT, MOTOR_AIN2_PIN, GPIO_PIN_RESET);
            break;

        case MOTOR_DIR_BACKWARD:
					// 0 1反转
            HAL_GPIO_WritePin(MOTOR_AIN1_PORT, MOTOR_AIN1_PIN, GPIO_PIN_RESET);
            HAL_GPIO_WritePin(MOTOR_AIN2_PORT, MOTOR_AIN2_PIN, GPIO_PIN_SET);
            break;

        case MOTOR_DIR_STOP:
					// 0 0 自由停止(惯性滑行）
        default:
            HAL_GPIO_WritePin(MOTOR_AIN1_PORT, MOTOR_AIN1_PIN, GPIO_PIN_RESET);
            HAL_GPIO_WritePin(MOTOR_AIN2_PORT, MOTOR_AIN2_PIN, GPIO_PIN_RESET);
            break;
        }
        break;

    case MOTOR_RIGHT:
        switch (dir) {
        case MOTOR_DIR_FORWARD:
            HAL_GPIO_WritePin(MOTOR_BIN1_PORT, MOTOR_BIN1_PIN, GPIO_PIN_SET);
            HAL_GPIO_WritePin(MOTOR_BIN2_PORT, MOTOR_BIN2_PIN, GPIO_PIN_RESET);
            break;

        case MOTOR_DIR_BACKWARD:
            HAL_GPIO_WritePin(MOTOR_BIN1_PORT, MOTOR_BIN1_PIN, GPIO_PIN_RESET);
            HAL_GPIO_WritePin(MOTOR_BIN2_PORT, MOTOR_BIN2_PIN, GPIO_PIN_SET);
            break;

        case MOTOR_DIR_STOP:
        default:
            HAL_GPIO_WritePin(MOTOR_BIN1_PORT, MOTOR_BIN1_PIN, GPIO_PIN_RESET);
            HAL_GPIO_WritePin(MOTOR_BIN2_PORT, MOTOR_BIN2_PIN, GPIO_PIN_RESET);
            break;
        }
        break;

    default:
        break;
    }
}
// 设置 PWM 占空比。
void Motor_SetPWM(Motor_TypeDef motor, uint16_t pwm)
{
    // 更新对应 PWM 通道的比较值。
    if (pwm > MOTOR_PWM_MAX) {
        pwm = MOTOR_PWM_MAX;
    }

    switch (motor) {
    case MOTOR_LEFT:
        __HAL_TIM_SET_COMPARE(&htim1, TIM_CHANNEL_1, pwm);
        break;

    case MOTOR_RIGHT:
        __HAL_TIM_SET_COMPARE(&htim1, TIM_CHANNEL_4, pwm);
        break;

    default:
        break;
    }
}

// 设置电机速度：正数前进，负数后退，0 停止。
void Motor_SetSpeed(Motor_TypeDef motor, int16_t speed)
{
    // 正数表示前进，负数表示后退，0 表示停止。
    speed = (int16_t)Motor_ClampPercent(speed);

    if (speed > 0) {
        Motor_SetDirection(motor, MOTOR_DIR_FORWARD);
        Motor_SetPWM(motor, (uint16_t)speed);
    } else if (speed < 0) {
        Motor_SetDirection(motor, MOTOR_DIR_BACKWARD);
        Motor_SetPWM(motor, (uint16_t)(-speed));
    } else {
        Motor_Stop(motor);
    }
}

// 停止单个电机。

void Motor_Stop(Motor_TypeDef motor)
{
    Motor_SetDirection(motor, MOTOR_DIR_STOP);
    Motor_SetPWM(motor, 0);
}
// 停止两个电机。
void Motor_StopAll(void)
{
    Motor_Stop(MOTOR_LEFT);
    Motor_Stop(MOTOR_RIGHT);
}

// 刹车单个电机。
void Motor_Brake(Motor_TypeDef motor)
{
    // 刹车模式：两个方向引脚都拉高。
    switch (motor) {
    case MOTOR_LEFT:
        HAL_GPIO_WritePin(MOTOR_AIN1_PORT, MOTOR_AIN1_PIN, GPIO_PIN_SET);
        HAL_GPIO_WritePin(MOTOR_AIN2_PORT, MOTOR_AIN2_PIN, GPIO_PIN_SET);
        break;

    case MOTOR_RIGHT:
        HAL_GPIO_WritePin(MOTOR_BIN1_PORT, MOTOR_BIN1_PIN, GPIO_PIN_SET);
        HAL_GPIO_WritePin(MOTOR_BIN2_PORT, MOTOR_BIN2_PIN, GPIO_PIN_SET);
        break;

    default:
        break;
    }

    Motor_SetPWM(motor, 0);
}

void Motor_BrakeAll(void)
{
    Motor_Brake(MOTOR_LEFT);
    Motor_Brake(MOTOR_RIGHT);
}

//前进 speed:0~100
void Motor_Forward(uint16_t speed)
{
    Motor_SetSpeed(MOTOR_LEFT, (int16_t)speed);
    Motor_SetSpeed(MOTOR_RIGHT, (int16_t)speed);
}

////后退 speed:0~-100
void Motor_Backward(uint16_t speed)
{
    Motor_SetSpeed(MOTOR_LEFT, -(int16_t)speed);
    Motor_SetSpeed(MOTOR_RIGHT, -(int16_t)speed);
}

//左转 左轮慢一点，右轮快一点。左轮半速 右轮全速
void Motor_TurnLeft(uint16_t speed)
{
    Motor_SetSpeed(MOTOR_LEFT, (int16_t)(speed / 2U));
    Motor_SetSpeed(MOTOR_RIGHT, (int16_t)speed);
}

// 右转：右轮慢一点，左轮快一点。
void Motor_TurnRight(uint16_t speed)
{
    Motor_SetSpeed(MOTOR_LEFT, (int16_t)speed);
    Motor_SetSpeed(MOTOR_RIGHT, (int16_t)(speed / 2U));
}

// 原地左旋：左轮后退，右轮前进。
void Motor_RotateLeft(uint16_t speed)
{
    Motor_SetSpeed(MOTOR_LEFT, -(int16_t)speed);
    Motor_SetSpeed(MOTOR_RIGHT, (int16_t)speed);
}

// 原地右旋：左轮前进，右轮后退。
void Motor_RotateRight(uint16_t speed)
{
    Motor_SetSpeed(MOTOR_LEFT, (int16_t)speed);
    Motor_SetSpeed(MOTOR_RIGHT, -(int16_t)speed);
}
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

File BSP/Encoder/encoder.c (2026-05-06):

/*
* ******************************************************************************
* @file encoder.c 
* @brief 编码器驱动 
* @describe 使用固定时间窗口计数 
* *****************************************************************************
*/
#include "encoder.h"


static uint16_t left_last_count = 0;
static uint16_t right_last_count = 0;

static int16_t left_last_delta = 0;
static int16_t right_last_delta = 0;

static uint32_t left_last_tick = 0;
static uint32_t right_last_tick = 0;


static uint16_t Encoder_ReadNow(Encoder_TypeDef encoder)
{
	  // 左电机对应编码器
    if (encoder == ENCODER_LEFT)
    {
        return (uint16_t)__HAL_TIM_GET_COUNTER(&htim2);
    }
		// 右电机对应编码器
    return (uint16_t)__HAL_TIM_GET_COUNTER(&htim3);
}


void Encoder_Init(void)
{
    uint32_t now;

		// 启动定时器编码器模式
    HAL_TIM_Encoder_Start(&htim2, TIM_CHANNEL_ALL);
    HAL_TIM_Encoder_Start(&htim3, TIM_CHANNEL_ALL);


		// 重置计数
    __HAL_TIM_SET_COUNTER(&htim2, 0);
    __HAL_TIM_SET_COUNTER(&htim3, 0);


    now = HAL_GetTick();


    left_last_count = 0;
    right_last_count = 0;

    left_last_delta = 0;
    right_last_delta = 0;

    left_last_tick = now;
    right_last_tick = now;
}


uint16_t Encoder_GetCount(Encoder_TypeDef encoder)
{
    return Encoder_ReadNow(encoder);
}


int16_t Encoder_GetDeltaCount(Encoder_TypeDef encoder)
{
    uint16_t now;

    int16_t delta = 0;


    now = Encoder_ReadNow(encoder);


    if (encoder == ENCODER_LEFT)
    {
        delta = (int16_t)(now - left_last_count);

        left_last_count = now;

        left_last_delta = delta;
    }
    else
    {
        delta = (int16_t)(now - right_last_count);

        right_last_count = now;

        right_last_delta = delta;
    }


    return delta;
}


void Encoder_Reset(Encoder_TypeDef encoder)
{
    uint32_t now = HAL_GetTick();


    if (encoder == ENCODER_LEFT)
    {
        __HAL_TIM_SET_COUNTER(&htim2, 0);

        left_last_count = 0;
        left_last_delta = 0;

        left_last_tick = now;

        return;
    }


    __HAL_TIM_SET_COUNTER(&htim3, 0);

    right_last_count = 0;
    right_last_delta = 0;

    right_last_tick = now;
}

// 重置所有编码器计数值和计时
void Encoder_ResetAll(void)
{
    Encoder_Reset(ENCODER_LEFT);

    Encoder_Reset(ENCODER_RIGHT);
}


Encoder_Direction_TypeDef Encoder_GetDirection(Encoder_TypeDef encoder)
{
    int16_t delta;


    delta = (encoder == ENCODER_LEFT)
            ? left_last_delta
            : right_last_delta;


    if (delta > 0)
    {
        return ENCODER_DIR_FORWARD;
    }

    if (delta < 0)
    {
        return ENCODER_DIR_BACKWARD;
    }

    return ENCODER_DIR_STOP;
}

//转每秒rps,Raw → Filtered → Output
static float Encoder_GetRawRPS(Encoder_TypeDef encoder)
{
    int16_t delta;

    uint32_t now_tick;
    uint32_t dt_ms;

    float dt_s;


    delta = Encoder_GetDeltaCount(encoder);


    now_tick = HAL_GetTick();


    if (encoder == ENCODER_LEFT)
    {
        dt_ms = now_tick - left_last_tick;

        left_last_tick = now_tick;
    }
    else
    {
        dt_ms = now_tick - right_last_tick;

        right_last_tick = now_tick;
    }


    if (dt_ms == 0)
    {
        return 0.0f;
    }


    dt_s = (float)dt_ms / 1000.0f;


    return ((float)delta)
            / ((float)ENCODER_PPR * dt_s);
}

// 转每秒rps(等于示波器上频率）
float Encoder_GetRPS(Encoder_TypeDef encoder)
{
	  //TODO:滤波返回
    return Encoder_GetRawRPS(encoder); //直接返回
}


// 返回每分钟转数rpm
float Encoder_GetRPM(Encoder_TypeDef encoder)
{
	  //TODO:滤波返回
    return Encoder_GetRawRPS(encoder) * 60.0f;//直接返回
}

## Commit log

2026-05-06 阶段一：各模块测试成功完成
    [MG370直流减速电机支架加厚加肋板.SLDPRT, 平衡车底板一体.SLDPRT]
2026-05-06 更新readme格式添加drawio文档
2026-05-06 更新drawio链接

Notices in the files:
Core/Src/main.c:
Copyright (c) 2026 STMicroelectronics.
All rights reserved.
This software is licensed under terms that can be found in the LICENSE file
